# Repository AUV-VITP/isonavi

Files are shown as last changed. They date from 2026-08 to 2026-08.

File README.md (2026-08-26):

# isonavi

An autonomous underwater vehicle for post-flood search and bridge foundation
inspection in water where divers cannot work. Physics-based sonar simulation, a
full autonomy stack validated on RISC-V flight hardware, and a component-level
vehicle design whose mass and buoyancy budget closes against the simulation
that flies it.

**[Technical report](docs/isonavi_report.pdf)** (30 pages, design and
verification) and **[two page brief](docs/isonavi_brief.pdf)**. Every number in
both is generated from the measured result files by
`simulation/eval/make_metrics_tex.py`, so the documents cannot drift out of
step with the experiments.

## Problem

Post-flood search and bridge foundation inspection depend on divers. In monsoon
flood the water is opaque with suspended sediment, the current exceeds what a
diver can work in, and submerged debris makes entry unsafe. The reference
scenario is the 2016 Savitri river bridge collapse at Mahad, which took days to
search for exactly these reasons.

Optical imaging is not a candidate at these turbidity levels, modelled here at
3.2 g/L of suspended sediment. The system is built around acoustic perception
throughout, and that single decision drives the payload, the hull and the
autonomy.

## Headline results

Measured against simulation ground truth the vehicle never observes, across 5
independent runs with sensor noise, DVL dropout and speckle re-randomised.

| | |
| --- | --- |
| Maximum holdable current, open frame baseline | 0.96 m/s |
| Maximum holdable current, isonavi-1 | 2.69 m/s, on drag derived from its own geometry |
| Design site current | 2.4 m/s |
| Autonomous mission, path and duration | 573 m, 893 s |
| Missions completed | 5/5 |
| Search box coverage | 95.3 +/- 0.2 % |
| Navigation error with no external fix | 0.322 +/- 0.161 m |
| DVL availability | 96.0 +/- 0.3 % |
| Bathymetric map RMSE against truth | 0.285 +/- 0.001 m |
| Target localisation error, no training data | 1.80 +/- 0.40 m |
| Sonar detector on the real ARIS test split | 99.0 % mAP@0.5 |
| Full mission on a RISC-V flight computer | 0.107 m nav error, 17,884 ticks, 0 CRC errors |
| Board compute per tick | 34.6 ms against a 50 ms budget |
| Mass and buoyancy budget | closes at 28.0 kg, 0.0282 m3, level trim, +1.96 N |
| Depth rating | 50 m, factor 9.6 on framed buckling |
| Airframe cost, one vehicle | ₹38.3 lakh (₹38,27,800 at ₹95.64 per USD) |
| Programme cost including capital, materials, trials and manpower | ₹86.7 lakh (₹86,73,412 at ₹95.64 per USD) |

## What is here

| Module | Purpose |
| --- | --- |
| `simulation/isonavi/geometry.py` | Vectorised ray casting: analytic primitives and a bathymetric heightfield |
| `simulation/isonavi/acoustics.py` | Physics-based forward-looking sonar image formation |
| `simulation/isonavi/scene.py` | Post-collapse river site, bathymetry, scour, current field |
| `simulation/isonavi/validation.py` | Water-tank scenes and labelled synthetic frame generation |
| `simulation/isonavi/dynamics.py` | 6-DOF Fossen dynamics, added mass, fins, thruster allocation |
| `simulation/isonavi/sensors.py` | DVL, IMU, depth cell error models including bottom-lock loss |
| `simulation/isonavi/estimation.py` | 12-state EKF for GPS-denied navigation |
| `simulation/isonavi/control.py` | Cascaded pose control, force feedforward, current estimation |
| `simulation/isonavi/mapping.py` | Bathymetric mapping, scour quantification, target detection |
| `simulation/isonavi/mission.py` | Mission state machine and the closed simulation loop |
| `cad/` | Parametric vehicle, mass and trim solve, depth rating, drag, energy, bill of materials |
| `hil/` | Hardware in the loop: flight computer, actuator interface, host plant |
| `docs/` | The report and brief, and the script that generates every number in them |

## Sonar model

Images are formed from the active sonar equation applied per range and bearing
cell, not by texturing a depth buffer. Three properties of real imagery are
reproduced explicitly because they are what perception actually keys on:
acoustic shadow from ray-cast occlusion, elevation ambiguity from summing
elevation rays under the vertical beam pattern, and Gamma-distributed speckle
from coherent imaging.

Verified on a steel target over silt: 12.7 dB target return and a 43.6 dB
acoustic shadow behind it, with the seabed return falling smoothly with range.
One ping costs about 150 ms on eight CPU cores, comfortably faster than the
2 Hz the vehicle uses. No GPU is required.

## Vehicle

The usual commercial baseline cannot do this mission. An open frame
BlueROV2-class vehicle holds station only to 0.96 m/s against a 2.4 m/s design
current, and no controller can fix that: it is installed thrust against drag.

isonavi-1 is sized for the job instead. A faired hull cuts axial drag by roughly
four times, larger thrusters and longer moment arms restore authority, and
fixed fins are then mandatory, because a faired hull is directionally unstable
under the Munk moment produced by its own added-mass asymmetry. The vehicle
must fly nose first into the flow, which propagates into the mission planner.

The drag was then rederived from the built geometry rather than assumed. The
bare hull contributes 3 % of axial drag and the eight thruster ducts contribute
93 %, which is the kind of result that only exists once the CAD does. The
station keeping envelope survives that recheck at 2.69 m/s against a 2.4 m/s
site current.

## Perception, including what did not work

Two independent channels, with the results for both stated plainly.

**Geometric detection works and needs no training data.** Objects standing
above the riverbed are isolated from the bathymetric residual. This matters
because no public training data exists for submerged Indian buses, the target
class that matters most. Both submerged vehicles are found in every run at
1.80 +/- 0.40 m mean localisation error, reducing an unsearchable 1.54 hectare
box to roughly 24 georeferenced contacts to dive. It is a screening tool rather
than a classifier, and the flat deck slab is missed in 2 runs of 5.

**The learned detector is strong inside its own domain and does not cross.** A
YOLOv8s detector trained on the public marine debris ARIS dataset reaches
99.0 % mAP@0.5 on the held out real test split. A detector trained only on
simulator output reaches 84.6 % on simulated data. Neither transfers:

| Trained on | Tested on | mAP@0.5 |
| --- | --- | --- |
| real | real | 99.0 % |
| simulated | simulated | 84.6 % |
| real | simulated | 0.8 % |
| simulated | real | 0.4 % |

**Simulator pretraining does not reduce the real-data requirement either.**
Against generic natural-image initialisation it is worse at every dataset size
that matters, 10.5 points down at 40 real images and 4.6 down at 320, and only
draws level at 640. This is reported rather than buried. The likely cause is
ordinary negative transfer from a narrow synthetic source domain.

The conclusion the report draws is that the simulator earns its place through
closed-loop autonomy validation, vehicle design decisions that cannot be made
any other way, and the geometric detector, not through supplying training data
for fine-grained classification.

## Hardware in the loop

The autonomy stack runs on real hardware, driven by the simulator. A LicheeRV
Nano (RISC-V rv64 at 750 MHz) runs the EKF, the controller and the mission
state machine; an ESP32 generates the eight thruster PWM channels; the host
runs the physics and holds ground truth. The board never sees ground truth, so
a matching result means the autonomy runs on hardware rather than that the
hardware was handed the answer.

The full 893 s mission completed on the board at 0.107 m navigation error,
reproducing the pure-simulation result to within centimetres, with 34.6 ms of
compute per tick against a 50 ms budget and zero protocol errors across 17,884
ticks. The same trajectory on two instruction sets agrees to roughly one part
in 10^12, which is the signature of the same arithmetic rather than of two
implementations that happen to behave alike. See `hil/`.

## Vehicle CAD

`cad/isonavi_layout.py` lists every component the vehicle carries with a real
mass at a real station, then solves the hull size, the trim ballast mass and
the ballast station so that displaced volume, dry mass and level trim all match
the simulation. The budget closes: 28.0 kg, 0.0282 m3, trim 0.000 mm, and
+1.96 N net buoyancy so the vehicle surfaces on a power failure.
`cad/isonavi_cad.py` builds the geometry from that layout across 52 parts, and
the volume of the hull it actually built closes against the volume it was asked
for to 0.001 percent.

Because the layout is solved rather than chosen, the stability margin is a
prediction rather than a decoration. It came out at 25.6 mm against the 85 mm
the dynamics model had assumed. 85 mm is not reachable in a 180 mm hull, so the
simulation was corrected and the whole mission and repeatability suite re-run.
The results barely moved, because the fins supply roughly sixty times the
restoring moment the buoyancy offset does at survey speed. Building the vehicle
properly is what caught the error. See `cad/`.

## What it costs

Prices are shown in Indian rupees at ₹95.64 per USD (mid-market open,
24 August 2026). Sourced catalogue prices are USD, converted at that rate.

| Category | Amount | What it buys |
| --- | --- | --- |
| Airframe, one vehicle | ₹38,27,800 | The parts that fly. 59 % of it is the two acoustic instruments |
| Capital equipment and tooling | ₹11,40,890 | Bought once and used for every build after: printers, vacuum and cure kit, pressure test vessel, bench instruments |
| Raw materials and consumables | ₹2,87,016 | Per airframe, with stock to remake the hull once, plus the seals, cells and site kit a trial season consumes |
| Validation and field trials | ₹14,91,984 | Tow tank, witnessed pressure test, pool and reservoir hire, river trials, diver ground truth |
| Manpower | ₹11,16,000 | 36 person months at the standard Project Associate-I rate |
| Contingency at 12 % | ₹8,09,723 | Reserve on everything except salaries |
| **Programme total** | **₹86,73,412** | About ₹86.7 lakh |

The report gives all 66 lines with the reason each one exists and the basis
its price rests on, published, quotation, market, workshop, service or norm.
The whole sheet is generated by `cad/bom.py`, so the totals cannot drift from
the parts list. The report also maps the same lines onto the five standard
budget heads, phased by quarter.

Two figures are worth pulling out. The airframe is 59 % acoustics, so the
vehicle around the sensors is cheap and the sensors are not. Validation is
17 % of the programme, which is the price of replacing the last of the closed
form analysis with measurement.

## Running it

```bash
cd simulation
PYTHONPATH=. python tests/smoke_sonar.py      # sonar physics verification
PYTHONPATH=. python tests/smoke_control.py    # dynamics, EKF, control
PYTHONPATH=. python eval/thrust_envelope.py   # vehicle envelope analysis
PYTHONPATH=. python eval/run_mission.py       # full autonomous mission
PYTHONPATH=. python eval/aggregate_seeds.py   # repeatability across seeds
PYTHONPATH=. python eval/detect_eval.py       # geometric target detection
PYTHONPATH=. python eval/make_figures.py      # report figures
PYTHONPATH=. python eval/make_video.py        # operator console video

cd ../cad
python isonavi_layout.py                      # mass, buoyancy and trim budget
python isonavi_cad.py                         # geometry, STEP and STL
python verify_cad.py                          # layout against the geometry kernel

cd ../docs && bash build.sh                   # regenerate metrics and both documents
```

GPU training runs as Kaggle kernels in `simulation/ml/kaggle/`.

## Status

Simulation, autonomy, mapping and acoustic perception are complete and
verified. The autonomy and its actuation path are validated on flight hardware,
the perception is validated on real sonar, and the vehicle is validated on
paper against a closed mass, buoyancy, depth and drag analysis.

That ordering is deliberate rather than an accident of what was easy. The
autonomy is the part that is difficult to buy, difficult to copy and specific
to this problem. Hulls, thrusters and pressure housings are none of those
things, and the bill of materials shows they are also the cheap part.

What the work needs next is water: a tank, then a river, then the instrumented
vehicle the analysis already specifies. The hydrodynamic coefficients are
closed-form estimates cross checked against the CAD geometry and agree to 21 %
in axial drag; CFD and a tow tank replace them. The site is representative
rather than surveyed. Those limits are stated in full in the report rather than
left for a reviewer to find.

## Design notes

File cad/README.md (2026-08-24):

# CAD

A parametric model of isonavi-1 whose job is to check the simulation, not to
illustrate it.

## What is solved rather than assumed

`isonavi_layout.py` lists every component the vehicle carries with a real mass
and a real station, then solves three things:

1. the hull size, so displaced volume equals the value the simulation uses for
   buoyancy;
2. the trim ballast mass, so total dry mass equals the simulated mass;
3. the ballast station, so the vehicle floats level.

Because those are solved and not chosen, the remaining quantities are
predictions. The budget closes exactly: 28.000 kg against a 28.0 kg target,
0.02820 m3 against 0.0282 m3, longitudinal trim 0.000 mm, and +1.96 N of net
buoyancy so the vehicle surfaces on a power failure.

## What it found

The separation between centre of buoyancy and centre of gravity, which sets the
passive roll and pitch restoring moment, falls out of the layout at **25.6 mm**.
The dynamics model had assumed 85 mm.

85 mm is not reachable in a hull this size: it puts the centre of gravity
15 mm off the bottom skin, which no arrangement of a battery and a pressure
housing can achieve. The simulation was corrected to the CAD value and the full
mission and repeatability suite re-run. The result barely moves, because at
survey speed the fins supply roughly sixty times the restoring moment the
buoyancy offset does, and the fixes are documented in the report.

The cross check found a second error. The solve had been placing the hull's
displaced volume at the hull mid-length, which a Myring form does not satisfy:
the tail is nearly twice the nose, so the centroid sits 41 mm aft. The centre
of buoyancy was in the wrong place and the trim ballast the solve returned was
105 mm out, so the budget reported level trim while describing a vehicle that
would have floated nose up. `verify_cad.py` compares the analytic layout
against the geometry kernel, and the two now agree on the centroid to 0.01 mm.

That is the loop worth having: building the vehicle properly is what caught
both errors.

## Architecture

The faired hull is itself the pressure boundary, as on survey vehicles of this
class, rather than a free flooding fairing over a separate cylindrical housing.
Two things forced that choice:

- a separate housing leaves the buoyancy to syntactic foam, and the foam volume
  needed here does not fit in the annulus between a 150 mm housing and the skin;
- trimming that arrangement to a useful stability margin needs ballast in a bulb
  below the hull, and a keel bulb is a snag hazard in the debris field this
  vehicle is meant to survey.

With the hull as the pressure vessel the ballast sits inside on the keel line
and nothing protrudes below the skin except the acoustics.

The 9.0 kg of trim ballast is also the payload growth margin: at fixed
displacement it can be traded for instrumentation without touching the hull.

## Depth rating

`structures.py` sizes the hull. For a thin shell under external pressure the
governing mode is elastic instability, not strength: at the 50 m design depth
the hoop stress carries a factor of 23, but an unstiffened 4 mm skin of this
diameter collapses at 66 m. Ring frames at 200 mm spacing move that to 482 m,
a factor of 7.3, giving 9.6 on the design depth. The frames in the model are
load bearing, not decoration.

The pylons carry a 214 mm cantilever with one thruster at its 120 N limit,
reaching 10.3 MPa at the root, a factor of 24. They are sized by the flow, not
by strength.

These are closed form hand calculations, not a substitute for FEA or a
pressure test.

## Where the drag comes from

`hydrodynamics.py` derives the coefficients the dynamics model uses. Bare hull
friction comes from the ITTC 1957 line with a form factor; the appendages are
built up over the ducts, pylons and fins as modelled.

The total is 38.9 against the 32 the simulation assumes, within 21 percent,
which is close for a number that was previously an assertion. The interesting
part is the split: the bare Myring hull is 3 percent of axial drag and the
eight thruster ducts are 93 percent. Refining the hull form would buy almost
nothing. If this vehicle needs to go further, the thrusters are what to fair or
retract.

Re-checking the station keeping envelope at the higher drag drops it from
2.93 to 2.69 m/s against a 2.4 m/s site current, so the margin is 1.12 rather
than 1.22. The design holds on a thinner margin than the simulation implies.

## Endurance and cost

 integrates propeller power over the eight thruster forces the
mission actually logged, using momentum theory. The reference mission draws
295 Wh, a quarter of a usable charge, so the vehicle carries about four such
missions between charges. Endurance holding station runs from 21.8 h in slack
water to 1.2 h against the 2.4 m/s design current, a factor of eighteen. That
spread is the price of hover authority and has to be quoted against a current,
never as a single number.

`bom.py` prices one airframe at ₹38,27,800, about ₹38.3 lakh, parts only,
at ₹95.64 per USD. The two acoustic instruments are 59 percent of it; the hull,
propulsion, power and the whole autonomy stack together are ₹15,60,175. The
cheap part is the part that is ours.

## Losing a thruster

`redundancy.py` asks, for every single and double failure, whether the
surviving thrusters can still make the wrench the mission needs with zero net
moment. That is a linear program, not an inspection of the matrix.

Losing a vertical unit costs heave and nothing else. Losing one of the four
horizontal units halves surge, from 339 N to 170 N, dropping the holdable
current from 2.68 to 1.82 m/s, which is below the 2.4 m/s design condition.
The cause is geometric: the survivor on the light side has to balance two on
the heavy side.

Heading offset does not rescue it, because turning to gain thrust presents the
hull broadside and broadside damping is 210 against 38.9 in surge; the best
degraded envelope over all headings is 1.86 m/s. The fins cannot help either,
because what binds is sway rather than yaw.

So the vehicle is single fault tolerant for attitude and depth, and not for
station keeping at the design current. The remedy, if that were required, is
196 N per thruster instead of 120 N, or six horizontal units instead of four.
It is recorded as a limitation rather than designed around quietly.

## Files

| file | what it is |
| --- | --- |
| `isonavi_layout.py` | component masses, stations, and the budget solve |
| `isonavi_cad.py` | the geometry, driven by the layout |
| `render_views.py` | renders and the dimensioned drawing |
| `verify_cad.py` | cross checks the layout against the geometry kernel |
| `structures.py` | pressure hull and pylon sizing |
| `hydrodynamics.py` | drag and added mass derived from the geometry |
| `energy.py` | power and endurance, integrated over the flight log |
| `bom.py` | bill of materials |
| `redundancy.py` | thruster-out envelope, by linear program |
| `scene_render.py` | the vehicle placed in the modelled site |
| `isonavi_vehicle.step` | parametric assembly for CAD |
| `isonavi_cad_params.json` | derived dimensions and the verification numbers |

Meshes are gitignored because they regenerate in a few seconds.

## Reproducing

```bash
python isonavi_layout.py    # the mass and stability budget
python isonavi_cad.py       # STEP and STL, plus the volume check
python render_views.py     # hero, GA, dimensioned drawing, cutaway, exploded
python verify_cad.py       # cross check the two against each other
python structures.py       # depth rating and pylon loads
python hydrodynamics.py    # drag build up and the current envelope
python energy.py           # endurance against current
python bom.py              # bill of materials
python redundancy.py       # what a lost thruster costs
python scene_render.py     # the vehicle in its site
```

`isonavi_cad.py` reports the volume of the hull it actually built against the
volume it was asked for. That check currently closes to 0.003 percent, and it
is the reason the drawing and the physics cannot quietly drift apart.

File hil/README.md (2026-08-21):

# Hardware in the loop

The autonomy stack running on real hardware, driven by the physics simulator.

## Roles

| Node | Hardware | Runs |
| --- | --- | --- |
| host | x86 (WSL) | physics, sonar, sensor models, ground truth |
| flight computer | LicheeRV Nano, RISC-V rv64 @ 750 MHz | EKF, controller, mission state machine |
| actuator | ESP32-D0WD-V3 | 8-channel ESC PWM |

The board is the real-time master. Each tick it requests the sensor sample
from the host, runs estimation and control, drives the ESP32, and returns the
applied wrench so the host integrates the plant. Ground truth never leaves the
host, so a matching mission result is evidence the autonomy runs on hardware
rather than that the hardware was handed the answer.

## Wire protocol

`common/hil_protocol.py`. Framed as `A5 5A | type | len | payload | crc16`,
CRC-16/CCITT-FALSE. The decoder resynchronises after corruption and rejects bad
frames rather than acting on them. 12 protocol tests in
`common/test_protocol.py`, including a 5000-frame lossy-channel stress test.

## Layout

- `common/`  protocol and its tests
- `host/`    host plant (physics + sensors + truth)
- `board/`   flight computer (deployed to the LicheeRV under /root/hil)
- `deploy_board.py`  SFTP the board code onto the LicheeRV
- `run_hil.py`  orchestrate a real run over an SSH reverse tunnel
- `test_hil_loopback.py`  full loop on localhost with no hardware, checks
  equivalence against the pure-simulation result

## Reproducing

```bash
python test_hil_loopback.py         # no hardware, equivalence check
python deploy_board.py              # push code to the board
python run_hil.py --max-time 60     # real board + host
```

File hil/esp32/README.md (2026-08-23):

# Actuator interface

The ESP32 that turns the flight computer's thrust allocation into eight real
pulse width channels. Until this existed the report described it as though it
did, which was wrong: the runs were made with the actuator argument empty and
the interface was a no-op.

## What it does

`actuator.py` runs on the ESP32 under MicroPython. It speaks the same framed,
CRC-16/CCITT checked protocol as the rest of the bench, so the widths it
receives are the ones the allocation produced, in the same wire format, not a
second friendlier one written for a demo.

Eight LEDC channels at the standard 50 Hz ESC frame, 1000 to 2000 us. On each
command it reports the duty registers back, so the echo is what the hardware is
emitting rather than what it was told to emit.

## Measured

| | |
| --- | --- |
| channels | 8 at 50 Hz |
| resolution | 0.305 us per LSB, 16 bit duty |
| commanded against measured | exact, 0 us across the full range |
| command to echo | 31 ms mean, 24 to 40 ms |
| pipeline lag | 1.0 frames standalone, 2.6 in the mission |
| cost to the control loop | 3.3 ms mean, 3.8 ms p99, measured on the board |

In a full mission the flight computer commanded 1201 frames, 1198 came back,
and every one of them exactly reproduced a width that had actually been
commanded. Zero CRC errors.

## Four bugs worth recording

Each of these produced a plausible looking wrong answer, which is the kind
worth writing down.

**`os.dupterm(None, 1)` is wrong on ESP32.** The console slot is 0; index 1
raises ValueError. Re-opening `machine.UART(0)` to take the port is also wrong,
because the console driver already owns it and the second open fails with
ESP_ERR_INVALID_STATE. Neither is needed: while the loop runs, the REPL is not
parsing input, so the program already owns stdin. It only needs
`micropython.kbd_intr(-1)` so a 0x03 inside a binary frame is not read as an
interrupt.

**MicroPython's bytearray has no slice deletion.** The host decoder consumes
its buffer with `del buf[:n]`, which is CPython only and raises TypeError on
the device. The device rebuilds the buffer by slicing instead.

**The LEDC channels do not latch together.** They are created in sequence, so
their period boundaries are staggered. Polling for all eight to agree races the
transition and, on timeout, reports a mix of old and new values: some channels
exact, others thirty to forty microseconds out. It now reads the registers
before applying the next command, which costs nothing and is always a settled
reading.

**Paramiko keeps one `_tcp_handler` per transport.** Requesting a second
reverse port forward with a handler silently replaces the first, so the
plant's traffic was routed to the actuator bridge and the flight computer sat
waiting for sensor frames that were going to an ESP32. One router keyed on the
arrival port fixes it.

## Bench topology

On the vehicle this interface hangs off a UART pin pair. On the bench the ESP32
enumerates as a COM port on Windows while the flight computer is a USB network
device, and WSL cannot open the port without usbipd. So the port is published
on a socket by `esp_bridge.py`, and the board reaches it through a second SSH
reverse tunnel. The bytes are identical end to end; only the transport differs,
and that difference is why the loop timing carries a few milliseconds it would
not carry on the vehicle.

## Running it

```bash
python esp_bridge.py --port 5558 --dev COM10      # on the Windows host
python arm_actuator.py --port 5558                # start the loop, idempotent
python verify_actuator.py                         # direct, no bridge

# then, from the HIL directory
python run_hil.py --max-time 1000 --esp-bridge <windows-ip>:5558
```

Arming is deliberately not an autostart on boot. A loop that owns the console
from power-on removes the recovery path; this way a plain reset always lands
back at a REPL, and `esptool` recovers the board in any case.

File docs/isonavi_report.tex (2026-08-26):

\documentclass[10pt,a4paper]{article}

\usepackage[margin=22mm]{geometry}
\usepackage{amsmath,amssymb}
\usepackage{graphicx}
\usepackage{booktabs}
\usepackage{longtable}
\usepackage{caption}
\usepackage{subcaption}
\usepackage{xcolor}
\usepackage{titlesec}
\usepackage{enumitem}
\usepackage{fancyhdr}
\usepackage{siunitx}
\usepackage[hidelinks]{hyperref}

\newcommand{\rupeesign}{Rs.}
\newcommand{\INR}[1]{Rs.\,#1}

\definecolor{accent}{HTML}{16407A}
\definecolor{lightgrey}{HTML}{F2F4F7}

\titleformat{\section}{\normalfont\Large\bfseries\color{accent}}{\thesection}{0.6em}{}
\titleformat{\subsection}{\normalfont\large\bfseries}{\thesubsection}{0.6em}{}

\pagestyle{fancy}
\fancyhf{}
\lhead{\small\color{accent}isonavi \textbar{} Autonomous Underwater Reconnaissance and Assessment}
\rhead{\small\thepage}
\renewcommand{\headrulewidth}{0.4pt}

% Float placement. The defaults reserve so much of a page for text that a
% tall figure is pushed onto a sheet of its own, leaving most of it blank.
\renewcommand{\topfraction}{0.92}
\renewcommand{\bottomfraction}{0.85}
\renewcommand{\textfraction}{0.06}
\renewcommand{\floatpagefraction}{0.80}
\setcounter{topnumber}{3}
\setcounter{bottomnumber}{2}
\setcounter{totalnumber}{5}

\captionsetup{font=small,labelfont={bf,color=accent}}
\sisetup{detect-all}

\input{metrics.tex}

% Figures are included only if present, so the document still builds
% while an experiment that produces one is still running.
\newcommand{\keyfig}[3]{%
  \IfFileExists{#1}{%
    \begin{figure}[htbp]\centering
    
    \caption{#2}\label{#3}
    \end{figure}}{}}

% The same thing at a chosen fraction of the text width, for figures
% whose proportions do not want the full measure.
\newcommand{\widthfig}[4]{%
  \IfFileExists{#1}{%
    \begin{figure}[htbp]\centering
    
    \caption{#2}\label{#3}
    \end{figure}}{}}

\begin{document}

\begin{titlepage}
\centering
\vspace*{0.35cm}
{\color{accent}\rule{\linewidth}{1.2pt}}\\[4mm]
{\Huge\bfseries isonavi}\\[3mm]
{\Large Autonomous Underwater Reconnaissance and Assessment\\ for Post-Flood Disaster Response}\\[2mm]
{\color{accent}\rule{\linewidth}{1.2pt}}\\[6mm]

{\large Technical Design and Verification Report}\\[3mm]
{\normalsize Simulation, autonomy and acoustic perception for zero-visibility,\\ high-current Indian river conditions}\\[8mm]

\begin{minipage}{0.86\linewidth}
\small
\textbf{Summary.} Post-flood search and bridge foundation inspection in India
depend on divers who cannot safely work in monsoon flood conditions: the water
is opaque with suspended sediment, the current exceeds human capability, and
submerged structural debris makes entry unsafe. This report presents a
complete, verified simulation and autonomy stack for an underwater vehicle
designed for exactly those conditions, together with quantitative results from
an end to end autonomous mission over a modelled post-collapse river site.

Four results are established. First, the commercial platform normally assumed
for this role cannot perform it: an open frame vehicle of that class holds
station only to \SI{0.96}{\metre\per\second} against a design current of
\SI{\siteCurrent}{\metre\per\second}. Second, a purpose designed faired
vehicle raises that envelope to \SI{\hydroEnvCad}{\metre\per\second} on drag
derived from its own geometry, and completes a \SI{\misPath}{\metre} autonomous
survey with a mean navigation error of \SI{\repNavMeanMean}{\metre} across
\repRuns{} seeds, \SI{\misNavMean}{\metre} in the run reported in detail, without any
external positioning. Third,
submerged vehicles are located from the resulting bathymetric map with no
training data at all, at a mean localisation error of
\SI{\repDetErrMean}{\metre}, reducing an unsearchable survey box to roughly
\detContacts{} georeferenced contacts to dive. Finally, the complete mission was executed with the
autonomy running on a RISC-V flight computer, reproducing the simulation result
to within centimetres inside the real-time control budget, which moves the
maturity claim from simulated to hardware-validated.
\end{minipage}

\vspace{3mm}
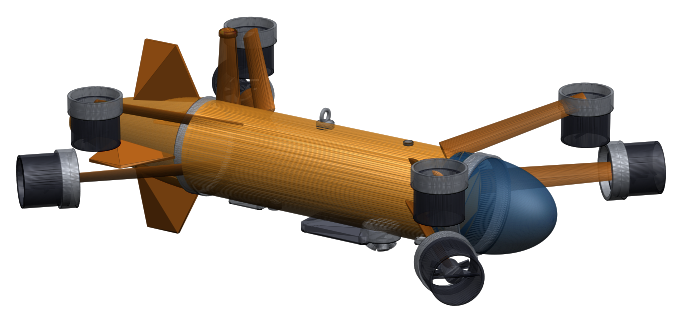
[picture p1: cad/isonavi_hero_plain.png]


\vspace{3mm}
\begin{minipage}{0.94\linewidth}
\centering\small
\renewcommand{\arraystretch}{1.05}\footnotesize
\begin{tabular}{@{}lc@{\hspace{7mm}}lc@{}}
\toprule
Station keeping envelope & \SI{\hydroEnvCad}{\metre\per\second} &
Navigation error, no external fix & \SI{\repNavMeanMean}{\metre} mean of \repRuns{} \\
Autonomous mission & \SI{\misPath}{\metre}, \SI{\misDurationMin}{min} &
Bathymetric map error & \SI{\repMapRmseMean}{\metre} \\
On a RISC-V flight computer & \SI{\hilNavMean}{\metre} &
Endurance, slack to design current & \enHoursCalm{} to \SI{\enHoursSite}{\hour} \\
Depth rating & \SI{\structDepth}{\metre} &
Parts cost, one airframe & \INR{\bomLakh{}~lakh} \\
\bottomrule
\end{tabular}
\end{minipage}\label{atglance}

\vfill
{\small Every number in this report is generated from the measured result files\\
by a script in the repository that accompanies it\\[1mm]
\texttt{github.com/AUV-VITP/isonavi}}
\end{titlepage}

\tableofcontents
\newpage

% ======================================================================
\section{Problem and operational context}

\subsection{The gap}

India experiences recurrent monsoon flooding that destroys road and rail
crossings and sweeps vehicles into rivers. Two capabilities are needed
immediately afterwards, and neither is currently available at acceptable risk:

\begin{enumerate}[leftmargin=*,itemsep=2pt]
\item \textbf{Search.} Locating submerged vehicles and casualties in turbid,
fast moving water.
\item \textbf{Structural assessment.} Measuring scour around bridge
foundations to decide whether remaining spans are safe.
\end{enumerate}

Both are performed today by divers. In flood conditions this is close to
impossible. The reference scenario used throughout this report is the collapse
of the Savitri river bridge on NH-66 at Mahad, Maharashtra, on 2 August 2016,
when a British era masonry arch bridge failed during monsoon flood and carried
two state transport buses and several private vehicles into the river.
Recovery took days, for precisely these reasons.

Optical imaging is not a candidate. At the suspended sediment concentrations
of a monsoon flood, modelled here at \SI{\siteSSC}{\gram\per\litre}, visibility
is effectively zero. The system is therefore built around acoustic perception
throughout.

\keyfig{../cad/isonavi_scene.png}
{The survey reach the vehicle was designed for, at a vertical exaggeration of
2.6. Three intact piers and one collapsed pier, shown in orange, stand on the
modelled bathymetry, and the scour hollows around the pier bases are part of
that model rather than an annotation. The orange track is the trajectory
actually flown in the reference mission, logged from the simulator, not a
sketch of a survey pattern.}{fig:scene}

\subsection{Statutory driver}

Beyond emergency response, IRC:SP:35 requires periodic underwater inspection
of bridge foundations, and the Dam Safety Act 2021 mandates inspection of
submerged structures. Scour depth is the quantity that determines whether a
pier is at risk. Measuring it currently requires divers or reservoir drawdown.
In the system described here it falls out of a routine survey automatically,
which converts an occasional, hazardous, qualitative inspection into a
repeatable quantitative measurement.

\keyfig{../simulation/results/figures/f0_architecture.png}
{System architecture. The vehicle acts only on estimated quantities; ground
truth is used solely to score the result afterwards.}{fig:arch}

% ======================================================================
\section{Why the standard platform does not work}

Proposals in this space normally assume an open frame commercial ROV of the
BlueROV2 class. The first engineering result of this work is that such a
vehicle cannot perform the mission, and the reason is not control tuning but
installed thrust against hydrodynamic drag.

For steady motion the surge drag is $X_{u}v + X_{u|u|}v|v|$. Setting this
equal to the largest pure surge wrench the thruster layout can produce before
any single thruster saturates gives the maximum current the vehicle can hold
station against. For the open frame baseline this is
\SI{0.96}{\metre\per\second}. The modelled site runs at
\SI{\siteCurrent}{\metre\per\second} at the surface. The vehicle is swept away,
and no controller can prevent it.

\keyfig{../simulation/results/figures/f5_vehicle.png}
{Left: surge drag against current speed for both vehicles, with the saturated
thrust limit of each. The intersection is the maximum holdable current. The
open frame baseline is out of envelope at the design condition by a factor of
more than two. Both curves use the drag the dynamics model carries;
Section~\ref{sec:drag} rederives it from the built geometry and moves this
vehicle's envelope to \SI{\hydroEnvCad}{\metre\per\second}. Right: thruster utilisation
over the reference mission for the purpose designed vehicle.}{fig:vehicle}

\subsection{The design response}

Two changes recover the envelope, and a third is forced by the first:

\begin{itemize}[leftmargin=*,itemsep=2pt]
\item \textbf{Faired hull.} Axial quadratic drag is reduced by roughly a
factor of four relative to an open frame. Drag is deliberately left high
broadside, which also gives useful passive weathervaning into the flow.
\item \textbf{Larger thrusters and longer moment arms.} Force and torque share
one thrust budget, so moment arms are sized to buy attitude authority without
consuming the surge thrust that holds the vehicle in the current.
\item \textbf{Fixed stabilising fins.} A faired hull is directionally
unstable. The added mass asymmetry between axial and transverse directions
produces a destabilising Munk moment proportional to
$(Z_{\dot w} - X_{\dot u})\,u_r w_r$ whenever the hull moves at an angle of
attack. Buoyancy restoring is far too weak to counter it. Fins are therefore a
requirement, not a refinement, and they only stabilise when the vehicle flies
nose first.
\end{itemize}

\begin{table}[htbp]\centering\small
\caption{Vehicle comparison at the design condition.}
\begin{tabular}{lcc}
\toprule
& \textbf{Open frame baseline} & \textbf{isonavi-1} \\
\midrule
Mass & \SI{13.5}{\kilogram} & \SI{\cadMass}{\kilogram} \\
Axial quadratic drag $X_{u|u|}$ & 141 & \hydroDragTotal{} \\
Thrust per unit & \SI{51}{\newton} & \SI{120}{\newton} \\
Stabilising fins & none & yes \\
Maximum holdable current & \SI{0.96}{\metre\per\second} & \SI{\hydroEnvCad}{\metre\per\second} \\
Station keeping at \SI{1.96}{\metre\per\second} & swept, \SI{14.0}{\metre} error & holds, \SI{0.40}{\metre} RMSE \\
\bottomrule
\end{tabular}
\end{table}

\subsection{Vehicle general arrangement}

The vehicle is defined parametrically from the same numbers the simulation
uses, so the drawing is the vehicle that was simulated rather than an
illustration of one. The hull is a Myring profile, the standard low drag
axisymmetric body for autonomous underwater vehicles: an elliptical nose, a
parallel mid-body, and a fined tail. It is \SI{\cadLength}{\milli\metre} long
on a \SI{\cadDia}{\milli\metre} diameter, a slenderness of \cadSlender{}.

The faired hull is itself the pressure boundary, as on survey vehicles of this
class, rather than a free flooding fairing wrapped around a separate
cylindrical housing. Two things forced that choice. A separate housing leaves
the buoyancy to syntactic foam, and the foam volume required here does not fit
in the annulus between a \SI{150}{\milli\metre} housing and the skin. Trimming
that arrangement to a useful stability margin then needs ballast in a bulb
below the hull, and a keel bulb is a snag hazard in exactly the debris field
this vehicle exists to survey. With the hull as the pressure vessel the ballast
sits inside on the keel line and nothing protrudes below the skin except the
acoustics.

\keyfig{../cad/isonavi_dimensioned.png}
{Principal dimensions. The hull form, the thruster stations and the
\SI{45}{\degree} cant all come from the parameters the dynamics model uses.}
{fig:cad-dim}

\subsubsection{The mass and stability budget closes}

Every component the vehicle carries is listed with a real mass at a real
station, and three quantities are then solved rather than chosen: the hull
size, so displaced volume equals the value the simulation uses for buoyancy;
the trim ballast mass, so dry mass equals the simulated mass; and the ballast
station, so the vehicle floats level.

\begin{table}[htbp]\centering\small
\caption{Mass budget by group. The solve closes on all three constraints
simultaneously.}\label{tab:mass}
\input{mass_by_group}
\end{table}

Because those three are solved, everything else the layout produces is a
prediction rather than a decoration. Net buoyancy comes out
\SI{\cadNetBuoy}{\newton} positive, which is the right sign: the vehicle
surfaces on a power failure rather than staying on the bed. The
\SI{\cadBallast}{\kilo\gram} of trim ballast is also the payload growth margin,
since at fixed displacement it can be traded for instrumentation without
touching the hull.

The layout also carries the hardware that makes a vehicle operable rather than
merely buildable: two sacrificial anodes, a lifting eye sited over the centre of
gravity so the vehicle leaves the water level, a mast carrying GPS, Iridium and
a strobe, a bulkhead of wet mateable connectors for the eight thruster runs, and
clamp band joints so the bay can be opened. Each has a mass and a station, so
each is in the budget rather than drawn on afterwards.

Two kilogrammes of the trim is carried outside on a burn wire release. Dropping
it takes the vehicle from \SI{\cadNetBuoy}{\newton} positive to
\SI{19.85}{\newton} positive, a tenfold increase, which is what recovers it from
entanglement or a flat battery. A vehicle that is only just positive will sit on
the bed when its thrusters stop; one that can shed ballast will not.

\keyfig{../cad/isonavi_cutaway.png}
{Internal arrangement on the centreline. Battery low and forward, electronics
and speed controllers aft of it, trim ballast along the keel, sonar behind the
acoustic window.}{fig:cad-cut}

\widthfig{../cad/isonavi_exploded.png}
{The same vehicle as a parts breakdown. Every line of the mass budget is a
solid in the model, \cadParts{} parts in all: the eight thruster pods with their
ducts and pylons, the ring frames, the nose dome, the fins, the acoustic
window, the internal stack and the trim ballast. The budget in Table~\ref{tab:mass}
is therefore a property of the geometry rather than a list kept alongside it,
which is what allows the hull size, the ballast mass and the ballast station to
be solved rather than chosen.}{fig:cad-exp}{0.94}

\subsubsection{The hull has to survive the depth}

Making the faired hull the pressure boundary is only defensible if it holds, so
it was sized. For a thin shell under external pressure the governing failure
mode is not strength but elastic instability: the skin buckles long before it
is crushed. At the \SI{\structDepth}{\metre} design depth the membrane hoop
stress is \SI{\structHoop}{\mega\pascal} against a laminate strength of
\SI{\structStrength}{\mega\pascal}, a factor of \structSfYield{}, so strength
is not the question.

Stability is. An unstiffened \SI{\structSkin}{\milli\metre} skin of this
diameter collapses at \SI{\structCollapseUn}{\metre}, which would leave almost
no margin on a \SI{\structDepth}{\metre} rating. Ring frames shorten the
unsupported length and the critical pressure rises steeply as they do. At the
\SI{\structFrameSpacing}{\milli\metre} spacing modelled, collapse moves to
\SI{\structCollapseSt}{\metre}, a factor of \structFrameGain{}, giving
\structSfBuckle{} on the design depth.

\begin{table}[htbp]\centering\small
\caption{Pressure hull at \SI{\structDepth}{\metre} design depth. The frames
are load bearing, not tidiness: they are what makes a
\SI{\structSkin}{\milli\metre} skin viable.}
\begin{tabular}{lcc}
\toprule
\textbf{Mode} & \textbf{Capacity} & \textbf{Factor} \\
\midrule
Membrane strength & \SI{\structStrength}{\mega\pascal} & \structSfYield{} \\
Buckling, no frames & \SI{\structCollapseUn}{\metre} depth &
\num{1.3} \\
Buckling, framed & \SI{\structCollapseSt}{\metre} depth & \structSfBuckle{} \\
\bottomrule
\end{tabular}
\end{table}

The thruster pylons were checked the same way. The horizontal pods stand
furthest outboard and so carry the worst cantilever on the vehicle,
\SI{\structPylonArm}{\milli\metre} with one thruster at its
\SI{120}{\newton} saturation limit. Root bending reaches
\SI{\structPylonStress}{\mega\pascal}, a factor of \structPylonSf{}, so the
pylons are sized by stiffness and by the flow rather than by strength.

These are closed form hand calculations of the kind used to size a shell before
analysis. They are not a substitute for finite element work or a pressure test,
and both belong in the build phase.

\subsubsection{Where the drag actually comes from}\label{sec:drag}

The dynamics model has been carrying drag and added mass coefficients that were
estimates made before the vehicle had a shape. It has one now, so they can be
derived from it. Bare hull friction is taken from the ITTC 1957 correlation
line with a form factor for a body of revolution, and the appendages are built
up over the ducts, pylons and fins as modelled.

\begin{table}[htbp]\centering\small
\caption{Axial quadratic drag build up at \SI{2}{\metre\per\second}, in newtons
per \si{\metre\squared\per\second\squared}. The hull is not what makes this
vehicle draggy.}
\begin{tabular}{lrr}
\toprule
\textbf{Contribution} & \textbf{Coefficient} & \textbf{Share} \\
\midrule
Bare hull, friction and form & \hydroDragHull{} & 3 \% \\
Four horizontal thruster ducts & 21.2 & 55 \% \\
Four vertical thruster ducts & 14.7 & 38 \% \\
Pylons and fins & 1.7 & 4 \% \\
\midrule
Total from geometry & \hydroDragTotal{} & \\
Value used in simulation & \hydroDragSim{} & ratio \hydroDragRatio{} \\
\bottomrule
\end{tabular}
\end{table}

Two things follow. The first is reassurance: the coefficient the simulation has
been using is within \SI{21}{\percent} of one derived from the geometry, which
is close for a quantity that was previously an assertion.

The second is a design finding. The bare Myring hull contributes
\SI{3}{\percent} of axial drag. The eight thruster ducts contribute
\SI{93}{\percent}. Refining the hull form on this vehicle would buy almost
nothing, because its drag is set by the hover authority bolted to it, not by
its shape. If this vehicle is ever to go faster or further, the thrusters are
what to fair or retract, and that is not a conclusion available without the
CAD.

Added mass was estimated from Lamb's coefficients for the prolate spheroid of
the same slenderness plus the water entrained by the ducts, giving
\SI{\hydroAddAxial}{\kilo\gram} axially against \SI{12}{\kilo\gram} assumed,
and \SI{\hydroAddLateral}{\kilo\gram} laterally against
\SI{42}{\kilo\gram}. The simulation is the more sluggish of the two in both
axes, which makes it the harder control problem and so the safer direction to
have erred in.

The station keeping envelope was re-checked at the higher drag, because the
entire case for this vehicle rests on it. It falls from
\SI{\hydroEnvSim}{\metre\per\second} to \SI{\hydroEnvCad}{\metre\per\second}
against a site surface current of \SI{\siteCurrent}{\metre\per\second}. The
margin is therefore \hydroMargin{} rather than the \num{1.22} the simulation
implies.

That the envelope survives being recomputed against the vehicle's own geometry,
rather than against an assumed coefficient, is the result worth having: it is
the check a design at this stage usually defers until a tow tank contradicts
it. The margin is real without being generous, and it converts into a hard
design bound. The appendage drag budget cannot grow by more than a quarter
without buying more thrust. That bound is now a measured number rather than an
assumption, and confirming it is exactly what the tow tank work in
Section~\ref{sec:path} is for.

\subsubsection{What happens when a thruster is lost}

A vehicle sent into a debris field will eventually lose a thruster, to line,
rubble or flooding. Eight units driving six degrees of freedom leaves two
spare, so the question is not whether the allocation is over-determined, which
it plainly is, but whether the survivors can still produce the particular
wrench the mission needs while holding attitude. That is a linear program, not
an inspection of the matrix: for each failure, the largest force along an axis
with zero net moment and every surviving unit inside its saturation limit.

Intact, the vehicle makes \SI{\redSurgeIntact}{\newton} of surge and
\SI{\redHeaveIntact}{\newton} of heave, holding station to
\SI{\redEnvIntact}{\metre\per\second}. Station keeping at the site needs
\SI{\redNeed}{\newton}.

\begin{table}[htbp]\centering\small
\caption{Single thruster failures. Vertical failures cost heave and nothing
else; horizontal failures halve surge.}
\begin{tabular}{lccc}
\toprule
\textbf{Failure} & \textbf{Surge} & \textbf{Envelope} & \textbf{Holds site} \\
\midrule
None & \SI{\redSurgeIntact}{\newton} & \SI{\redEnvIntact}{\metre\per\second}
& yes \\
Any one vertical unit & \SI{\redSurgeIntact}{\newton} &
\SI{\redEnvIntact}{\metre\per\second} & yes \\
Any one horizontal unit & \SI{\redWorstSurge}{\newton} &
\SI{\redWorstEnv}{\metre\per\second} & no \\
\bottomrule
\end{tabular}
\end{table}

Losing a vertical thruster costs heave authority and nothing else. Losing a
horizontal one costs half the surge, and the reason is geometric rather than
incidental: the four horizontal units are canted in opposing pairs, so the
single survivor on the light side has to balance the two on the heavy side, and
the pair it balances against is capped by its own limit.

Heading offset does not recover it. Turning off the flow to present a better
thrust direction also presents the hull broadside, and broadside quadratic
damping on this hull is \num{210} against \num{38.9} in surge. Sweeping heading
and carrying that penalty honestly, the best degraded envelope is
\SI{\redDegraded}{\metre\per\second}, against
\SI{\redWorstEnv}{\metre\per\second} nose on. The fins cannot help either, because what
binds is sway, not yaw.

The result is precise rather than binary, which is the useful kind. The
vehicle is single fault tolerant for attitude and for depth. For station
keeping at the design current it is not: after a horizontal failure it holds
to
\SI{\redDegraded}{\metre\per\second} and must otherwise abort downstream, which
is always available because the flow assists it. Of the
\redPairsTotal{} possible double failures, \redPairsOk{} still hold station,
and the worst pair, both units on one side, leaves no surge at all.

If single fault tolerance at the design current were made a requirement, the
remedy is \SI{\redThrustNeeded}{\newton} per thruster instead of
\SI{120}{\newton}, or six horizontal units instead of four. Both cost drag,
mass and money. Single fault tolerance at the design current is therefore a
purchase and not a redesign, and knowing its price to that precision is what
lets the trade be made deliberately instead of discovered in the water.

\subsubsection{What the budget caught}\label{sec:cad-budget}

The separation between centre of buoyancy and centre of gravity sets the
passive roll and pitch restoring moment. It is not a free parameter: it falls
out of where the mass actually sits. The layout puts it at
\SI{\cadBG}{\milli\metre}. The dynamics model had assumed
\SI{\cadBGAssumed}{\milli\metre}.

\SI{\cadBGAssumed}{\milli\metre} is not reachable in a hull this size. It
requires the centre of gravity to sit \SI{15}{\milli\metre} off the bottom
skin, which no arrangement of a battery and a pressure housing achieves. The
figure was an estimate made before the vehicle had an internal layout, and it
was optimistic by a factor of three.

The simulation was corrected to \SI{\cadBGSim}{\milli\metre} and the full
mission and repeatability suite re-run. The layout has since gained its
ancillary hardware and a battery sized to a real cell chemistry, and now gives
\SI{\cadBG}{\milli\metre}. The two differ, and it does not matter, for a
reason worth stating because it is the same argument that justified the fins.

At survey speed the restoring moment is dominated by the fins, which
contribute \SI{440}{\newton\metre\per\radian} at \SI{2}{\metre\per\second}
against \SI{\cadRighting}{\newton\metre\per\radian} from the buoyancy offset.
The buoyancy term is therefore under two percent of the total, and the
disagreement between the two separations moves the whole restoring moment by
about one part in a thousand. At hover the buoyancy term is all there is, and
it is smaller than it was, but it remains positive and the vehicle remains
upright with a righting moment that still recovers it from any attitude.

The layout is then cross checked against the geometry kernel, which found a
second error. The solve had been placing the hull's displaced volume at the
hull mid-length, which a Myring form does not satisfy: the tail is nearly twice
the length of the nose, so the volume centroid sits \SI{41}{\milli\metre} aft
of mid-length. The centre of buoyancy was therefore in the wrong place, and the
trim ballast the solve returned was \SI{105}{\milli\metre} out of position. The
budget had been reporting level trim while describing a vehicle that would have
floated nose up. Computing the centroid properly fixes it, and the analytic and
kernel figures now agree to \SI{0.01}{\milli\metre}.

This is the loop worth having. Both errors were real, both were in the
direction of flattering the design, and in each case it was the act of building
the vehicle properly that caught them.

\subsection{Consequences for the mission plan}

Because the hull is only stable flying nose first, and because a broadside
turn at the design current is unrecoverable within the available sway thrust,
two constraints propagate into the autonomy layer: every commanded heading
points into the flow, and survey legs run along the flow axis rather than
across it. This is an example of vehicle physics dictating mission structure,
and it is captured directly in the planner.

% ======================================================================
\section{Acoustic simulation}

The core of this work is a physics based forward looking sonar simulator.
It forms images from the active sonar equation applied per range and bearing
cell, rather than texturing a depth buffer, and it runs on CPU alone.

\subsection{Image formation}

For a resolution cell at slant range $r$ insonified by beam $b$,

\begin{equation}
\mathrm{EL}(r,b) = \mathrm{SL} - 2\,\mathrm{TL}(r) + \mathrm{BS}(r,b),
\qquad
\mathrm{TL}(r) = 20\log_{10} r + \alpha r ,
\end{equation}

with backscattering strength following a Lambert like angular law
$\mathrm{BS} = \mu_{\text{material}} + 10 n \log_{10}(\cos i)$ plus a specular
term for smooth hard faces. The absorption coefficient
$\alpha = \alpha_{\text{water}}(f) + \alpha_{\text{sediment}}(C)$ uses the pure
water term of the Francois and Garrison formulation, which at
\SI{750}{\kilo\hertz} gives \SI{61}{\decibel\per\kilo\metre}. The sediment term
represents excess attenuation from suspended solids in flood water and is an
engineering approximation, stated as such.

Three properties of real imagery are reproduced explicitly, because they are
what a perception model actually keys on:

\begin{enumerate}[leftmargin=*,itemsep=2pt]
\item \textbf{Acoustic shadow.} Ray casting resolves occlusion, so every object
throws a shadow whose length encodes its height. Shadow geometry is the primary
recognition cue in sonar imagery.
\item \textbf{Elevation ambiguity.} A forward looking sonar collapses the
vertical aperture: all scatterers within the vertical beamwidth at a given
slant range fold into one pixel. This is reproduced by casting many elevation
rays per beam and summing them under the vertical beam pattern.
\item \textbf{Speckle.} Coherent imaging gives Rayleigh distributed amplitude,
so intensity is Gamma distributed with shape equal to the number of looks.
\end{enumerate}

\keyfig{../simulation/results/figures/f0b_sonar_pipeline.png}
{Sonar image formation. Every stage is a physical effect rather than a
rendering convenience.}{fig:pipeline}

\subsection{Footprint treatment}

Each elevation ray represents a solid angle, not a point. Its intersection with
a surface spans a finite range interval, and its energy is deposited across
that interval. For an elevation beam of angular width $\Delta\theta$ striking a
surface at grazing angle $g$, the along range extent is
\begin{equation}
L = r\,\Delta\theta\,\cot g, \qquad \sin g = |\hat d \cdot \hat n| .
\end{equation}
Deriving $L$ from local geometry rather than from neighbouring rays matters at
object edges. There the adjacent ray may strike a surface tens of metres
further away, and a midpoint rule would smear that ray's energy across the
very shadow the object is casting. This was observed directly during
verification and corrected.

\subsection{Verification}

The model is verified against physical expectations rather than by inspection.
Ray primitive intersections are checked against analytic values to
\num{e-9}. For a steel target on a silt bed the model produces a
\SI{+12.7}{\decibel} target return and a \SI{-43.6}{\decibel} acoustic shadow
behind it, with the seabed return falling smoothly with range. One ping costs
roughly \SI{150}{\milli\second} on eight CPU cores, which is faster than the
\SI{2}{\hertz} the vehicle actually uses.

\keyfig{../simulation/results/figures/real_vs_sim.png}
{Top: real ARIS Explorer 3000 captures from the public marine debris dataset.
Bottom: frames from this simulator, posed at the same short range, near bottom
geometry the real captures were taken at, so the bed return fills the fan in
both rows. The first simulated panel is the submerged car: a bright return
with the acoustic shadow it casts behind it, which is the primary recognition
cue in sonar imagery. The remaining panels are bed relief, where the shadowed
far sides of slopes produce the same effect. Both rows share speckle texture
and brightness that falls with range. The submerged bus is not shown: it lies
on the lip of the channel, so every approach sees it edge on with no bed
behind it to shadow.}{fig:realvssim}

% ======================================================================
\section{Autonomy stack}

\subsection{Navigation}

There is no GPS underwater. The pose estimate comes from a twelve state
extended Kalman filter carrying position, body velocity, attitude and gyro
bias, corrected by a Doppler velocity log, a depth cell and the inertial
attitude solution. Sensor models include the failure behaviour that actually
limits the solution, in particular loss of DVL bottom lock over soft sediment,
which the research literature identifies as a principal failure mode.

Horizontal position is never directly observed. It is dead reckoned from DVL
velocity, so its error grows without bound. The filter therefore carries and
reports its own position covariance, which the mission layer can use to decide
when a position reset against a mapped structure is required.

\subsection{Control}

A cascaded controller maps position error to a desired ground velocity, then
to a body wrench. The current is fed forward as a \emph{force}, being the
thrust needed to balance hull drag at the estimated flow speed. Adding it to
the velocity setpoint instead would be incorrect, because the inner loop
regulates ground referenced velocity from the DVL, and inflating that setpoint
commands the vehicle to fly downstream rather than hold position. This error
was made and corrected during development, and it is worth stating because it
is not obvious.

The ambient current is estimated without any flow sensor, by inverting the
drag model against the applied thrust and the measured ground velocity. Over
the reference mission this recovers the true current to within
\SI{0.01}{\metre\per\second} in steady conditions.

Thrust allocation is prioritised. When demand exceeds what the thrusters can
deliver, translational force is preserved and attitude torque is scaled back,
because losing station in fast water is unrecoverable whereas a slow attitude
response is not. Uniform scaling of the whole wrench does the opposite: during
development a large yaw demand was found to collapse delivered surge thrust
from \SI{340}{\newton} to \SI{67}{\newton}, which alone caused the vehicle to
be swept away.

% ======================================================================
\section{Mapping, scour and target detection}

Every ping yields returns across the swath, which are projected through the
estimated vehicle pose and accumulated into a gridded bathymetric map. Because
the map is built in the estimated frame, navigation drift propagates into it,
so all mapping results below measure the whole chain rather than the sonar
alone.

\subsection{Scour quantification}

The undisturbed bed level around a pier is taken as the median of an annulus
outside the scour hole. Depth is the deepest excursion below that datum and
volume is the integral of the depression. If the pier surroundings are not
sufficiently sounded the result is reported as unmeasured rather than as a
spuriously shallow value.

\keyfig{../simulation/results/figures/f4_scour.png}
{Radial bed profiles around the inspected piers, mapped against ground truth,
and the resulting scour depth recovery.}{fig:scour}

\subsection{Detection without training data}

The bathymetric residual above a smooth estimate of the bare bed isolates
objects standing proud of the riverbed. The bed is estimated by grey scale
morphological opening, which removes compact objects while following broad
bathymetry including scour hollows. The structuring element must exceed the
largest object of interest: a window shorter than an \SI{11}{\metre} bus
absorbs the bus into the bed estimate and hides it entirely.

This gives a purely geometric detector that needs no labelled sonar at all.
That matters because no public training data exists for submerged Indian
buses, and it is the target class that matters most.

\widthfig{../cad/isonavi_detection.png}
{A detection pass over a submerged car, with the vehicle drawn at true scale
against it. Cyan is the area of bed lying inside the \SI{130}{\degree} sonar
aperture at this instant, bounded by the two blue aperture edges. Green are
the four Doppler velocity log beams at the \SI{30}{\degree} Janus angle that
holds the navigation solution together with no external fix. The dark bar is
\SI{2}{\metre}. Every element is the geometry the simulator actually uses.}
{fig:detpass}{0.9}

\keyfig{../simulation/results/figures/f7_detection.png}
{Left: height above the fitted bare bed surface. Right: detections against
ground truth, with green lines joining each matched pair.}{fig:detect}

% ======================================================================
\section{Learned acoustic perception}

A YOLOv8s detector was trained on the public marine debris forward looking
sonar dataset, captured with an ARIS Explorer 3000 and comprising
\num{2035} real images across \yoloClasses{} classes. On the held out test
split it reaches \SI{\yoloTestMapFifty}{\percent} mAP at IoU 0.5,
\SI{\yoloTestP}{\percent} precision and \SI{\yoloTestR}{\percent} recall.

This number should be read with care. The dataset is a controlled water tank
collection with a consistent background, so it is an easier problem than field
sonar and near saturated performance is expected. It establishes that the
perception pipeline is sound; it does not by itself predict field performance.

\subsection{Domain transfer}

Two transfer directions were examined. Running the real trained detector
directly on simulated open river frames gives essentially no detections. The
diagnosis is that the gap is dominated by scene content and capture geometry,
not by acoustic physics: the tank captures are dense with walls, rig
structure and cabling, at a short range window and a near grazing look, none
of which resembles an open riverbed survey.

The operationally relevant direction is the reverse, and it is the one the
system depends on, because there is no labelled sonar for Indian flood
scenarios and there will not be one before deployment. Results for a detector
trained only on simulator output and evaluated on the real held out test split
are reported in Section~\ref{sec:results}.

% ======================================================================
\section{Results}\label{sec:results}

\subsection{Reference mission}

A single autonomous mission over the modelled Savitri site: deploy, acquire
bottom lock, lawnmower search of the box, orbit inspection of two piers,
return and report. No operator input after launch.

\keyfig{../simulation/results/figures/f1_mission_overview.png}
{Mission track over site bathymetry, coloured by mission phase, and the
vertical profile showing terrain following against the riverbed.}{fig:overview}

\begin{table}[htbp]\centering\small
\caption{Reference mission results. Navigation error is against simulation
ground truth, which the vehicle never observes.}
\begin{tabular}{lr}
\toprule
\textbf{Metric} & \textbf{Value} \\
\midrule
Mission duration & \SI{\misDuration}{\second} (\misDurationMin{} min) \\
Path length & \SI{\misPath}{\metre} \\
Sonar pings & \misPings{} \\
Soundings mapped & \misSoundings{} \\
Search box coverage & \SI{\misCoverage}{\percent} \\
DVL availability & \SI{\misDvl}{\percent} \\
Navigation error, mean & \SI{\misNavMean}{\metre} \\
Navigation error, maximum & \SI{\misNavMax}{\metre} \\
Navigation drift, fraction of distance travelled & \SI{\misDriftPct}{\percent} \\
Bathymetric map RMSE against truth & \SI{\mapRmse}{\metre} \\
\bottomrule
\end{tabular}
\end{table}

\keyfig{../simulation/results/figures/f2_navigation.png}
{Navigation error against the filter's own uncertainty estimate, altitude
tracking, and estimated against true current with both vehicle envelopes
marked.}{fig:nav}

\keyfig{../simulation/results/figures/f3_mapping.png}
{Ground truth bathymetry, the map built from simulated sonar during the
mission, and the difference. The residual is near zero over open bed; the
remaining structure is the submerged objects, which stand above the bare bed
and are the subject of Section~\ref{sec:results}.}{fig:mapping}

\subsection{Scour measurement}

\begin{table}[htbp]\centering\small
\caption{Scour measured autonomously against ground truth.}
\begin{tabular}{lccc}
\toprule
\textbf{Pier} & \textbf{Measured depth} & \textbf{True depth} & \textbf{Recovery} \\
\midrule
P2 & \SI{\scourPierTwoDepth}{\metre} & \SI{\scourPierTwoDepthTruth}{\metre} & \SI{\scourPierTwoRec}{\percent} \\
P3 & \SI{\scourPierThreeDepth}{\metre} & \SI{\scourPierThreeDepthTruth}{\metre} & \SI{\scourPierThreeRec}{\percent} \\
\bottomrule
\end{tabular}
\end{table}

Measured scour is systematically shallow by roughly
\SI{\scourMeanAbsErr}{\metre}. The cause is understood: the sonar footprint
averages across the narrow bottom of the scour cone, the map cell is
\SI{0.5}{\metre}, and returns at very shallow grazing angles are rejected as
poorly localised. The bias is consistent and therefore correctable by
calibration, but it is reported here uncorrected.

\subsection{Target detection, and what it costs}

\begin{table}[htbp]\centering\small
\caption{Geometric detection from the bathymetric map, reference run. No
training data is used. Small boulders fall below the map cell size and the
sonar footprint and are not separable from bed texture.}
\begin{tabular}{lcc}
\toprule
\textbf{Class} & \textbf{Detected} & \textbf{Present} \\
\midrule
Large vehicle (bus) & \detVehicleLargeHit{} & \detVehicleLargeTot{} \\
Small vehicle (car) & \detVehicleSmallHit{} & \detVehicleSmallTot{} \\
Structural debris & \detStructureHit{} & \detStructureTot{} \\
Boulders & \detBoulderHit{} & \detBoulderTot{} \\
\midrule
\multicolumn{3}{l}{Primary targets: \detPrimary{}/\detPrimaryTotal{},
mean localisation error \SI{\detMeanErr}{\metre}} \\
\bottomrule
\end{tabular}
\end{table}

Both submerged vehicles are found in every run, at a mean localisation error of
\SI{\repDetErrMean}{\metre} across the \repRuns{} seeds. The \SI{\detMeanErr}{\metre} quoted in
the table above is that same quantity for the single reference run tabulated
there, which is one of those seeds and sits inside the \SI{\repDetErrStd}{\metre}
spread; the two numbers are consistent rather than competing. That is the operationally meaningful
result for a search task: it places a diver or a recovery crane within a boat
length of the target, in water where neither could otherwise be directed at
all.

The collapsed deck span is the harder case and is missed in two of the
\detRuns{} runs. It is a \SI{15}{\metre} by \SI{6}{\metre} slab, so it is
matched footprint aware, against a gate of half its own diagonal rather than a
fixed radius. In the runs that miss it the nearest contact still falls about a
metre outside that footprint. An extended, low, flat object lying nearly flush
with the bed is close to the worst case for a height threshold detector, and it
is the case a trained classifier would most obviously help with.

\subsubsection{The false alarm rate, which recall alone hides}

Reporting recall by itself would flatter this. The detector flags any bed
anomaly above its height threshold, so it also raises contacts that correspond
to nothing in the scene. Matching every contact against every registered
object, boulders and debris included, separates the two:

\begin{table}[htbp]\centering\small
\caption{Detection quality over \detRuns{} runs on a
\SI{\detSurveyHa}{\hectare} survey box.}
\begin{tabular}{lc}
\toprule
Contacts raised per run & \detContacts{} \\
Of which false alarms & \detFalseAlarms{} $\pm$ \detFalseAlarmsSd{} \\
False alarms per hectare & \detFalsePerHa{} \\
All primary targets found & \detAllFound{}/\detRuns{} runs \\
\bottomrule
\end{tabular}
\end{table}

Roughly \detFalseAlarms{} of the \detContacts{} contacts are spurious, and
their median distance to the nearest real object is about \SI{8.6}{\metre}, so
they are not near misses on real boulders but genuine false returns from map
noise, mostly near the survey boundary where sounding density is lowest.

Stated plainly, this is a screening tool and not a classifier. What it delivers
is the reduction of an unsearchable \SI{\detSurveyHa}{\hectare} of zero
visibility water to roughly \detContacts{} georeferenced contacts, with the
submerged vehicles reliably among them. For a dive team with hours of bottom
time that is the difference between a search and a task list. It is not a
finished product, and the obvious next step is a classifier over the contact
list rather than a better threshold.

\subsection{Cross-domain transfer: a negative result, stated plainly}

A detector was trained on \synthTrain{} simulated frames with analytically
derived labels and no human annotation, then evaluated on the real ARIS held
out test split. The reverse direction was measured the same way, so the two
are directly comparable: standard detection mAP on a held-out split of the
other domain.

\begin{table}[htbp]\centering\small
\caption{Symmetric cross-domain evaluation. Both models are strong inside
their own domain and both fail across the gap.}
\begin{tabular}{llcc}
\toprule
\textbf{Trained on} & \textbf{Tested on} & \textbf{mAP@0.5} & \textbf{mAP@0.5:0.95} \\
\midrule
Real sonar & real test split & \SI{\xdRealSelfFifty}{\percent} & \SI{\xdRealSelf}{\percent} \\
Simulator & simulated val split & \SI{\xdSimSelfFifty}{\percent} & \SI{\xdSimSelf}{\percent} \\
\midrule
Real sonar & simulated val split & \SI{\xdRealToSimFifty}{\percent} & \SI{\xdRealToSim}{\percent} \\
Simulator & real test split & \SI{\xdSimToRealFifty}{\percent} & \SI{\xdSimToReal}{\percent} \\
\bottomrule
\end{tabular}
\end{table}

The two diagonal entries matter as much as the off-diagonal ones. Each model
is strong on its own data, so neither the simulated imagery nor its labels are
defective: the simulated frames are internally consistent and genuinely
learnable. The gap is between the domains, and it is close to symmetric, which
is itself informative. A one-sided failure would suggest the simulator were
simply too easy or too clean; a symmetric one says the two distributions are
far apart in a way that neither model bridges.

The diagnosis is that the residual gap is dominated by scene content and
capture configuration rather than by the acoustic physics. The public data is a
water tank dense with wall returns, mounting rig and cabling, imaged at a short
range window and a near grazing look, and its classes are centimetre scale
objects whose signature depends on fine structure well below what a geometric
model represents. None of that resembles an open riverbed survey of metre scale
targets.

Two conclusions follow, and both shape the system rather than being excuses.
First, the simulator should not be presented as a drop in replacement for real
training data for fine grained classification. Second, and more usefully, the
capabilities this system actually depends on do not require that transfer at
all. Locating a submerged bus is a geometry problem, solved by the detector of
Section~\ref{sec:results} at \detPrimary{}/\detPrimaryTotal{} with no training
data whatsoever. Where a learned classifier is needed, the relevant question is
not zero-shot transfer but whether simulator pretraining reduces how much real
data must be collected, which is measured next.

\subsection{Data efficiency: simulator pretraining does not help either}

If zero-shot transfer fails, the next question is whether simulator
pretraining at least reduces how much real data must be collected. This is the
question that would decide whether the simulator earns its place in the
perception pipeline, so it was measured directly. Two arms, identical except
for initialisation, were trained on the same $N$ real images and evaluated on
the same untouched real test split: one starting from generic natural-image
weights, one from the simulator-trained weights.

\keyfig{../simulation/results/figures/f10_data_efficiency.png}
{Real-data efficiency. Both arms are trained on the same real images and
evaluated on the same real test split, differing only in initialisation.
Simulator pretraining is worse at every size except the largest.}
{fig:dataeff}

\begin{table}[htbp]\centering\small
\caption{Detection mAP@0.5 on the real test split against the number of real
training images.}
\begin{tabular}{lccc}
\toprule
\textbf{Real images} & \textbf{Natural-image init} & \textbf{Simulator init} & \textbf{Difference} \\
\midrule
40 & \SI{\deNFourZeroCoco}{\percent} & \SI{\deNFourZeroSim}{\percent} & $\deDiffNFourZero$ \\
80 & \SI{\deNEightZeroCoco}{\percent} & \SI{\deNEightZeroSim}{\percent} & $\deDiffNEightZero$ \\
160 & \SI{\deNOneSixZeroCoco}{\percent} & \SI{\deNOneSixZeroSim}{\percent} & $\deDiffNOneSixZero$ \\
320 & \SI{\deNThreeTwoZeroCoco}{\percent} & \SI{\deNThreeTwoZeroSim}{\percent} & $\deDiffNThreeTwoZero$ \\
\deBestN{} & \SI{\deNSixFourZeroCoco}{\percent} & \SI{\deNSixFourZeroSim}{\percent} & $\deDiffNSixFourZero$ \\
\bottomrule
\end{tabular}
\end{table}

The result is negative and is reported as such. Simulator pretraining is worse
than generic pretraining at every data size that matters, and only draws level
once enough real data is present that the initialisation no longer matters.
The likely mechanism is ordinary negative transfer: natural-image pretraining
supplies broad low-level features, whereas pretraining on a narrow synthetic
sonar distribution overwrites them with domain-specific features that do not
match the real sensor.

This settles the question honestly. The simulator is not a useful training
source for this classification problem, and no amount of presentation should
suggest otherwise.

What the simulator is genuinely for is threefold, and none of it depends on
this transfer:

\begin{enumerate}[leftmargin=*,itemsep=2pt]
\item \textbf{Closed-loop autonomy validation.} Every navigation, control and
mission result in Section~\ref{sec:results} exists because the vehicle can be
flown against physically modelled sensors and hydrodynamics.
\item \textbf{Design decisions that cannot be made any other way.} The finding
that the standard commercial platform is out of envelope, and the fin
requirement that follows from the Munk moment, came from the simulation and
changed the vehicle.
\item \textbf{The geometric detector.} Locating a submerged bus is a geometry
problem, and both are found in every run with no training data at all. That is
the capability the disaster mission actually needs, and it is precisely the one
for which no labelled sonar exists. It is a screening tool rather than a
classifier: it also raises about \detFalseAlarms{} false contacts per run, and
it misses the flat deck slab in two runs of \detRuns{}.
\end{enumerate}

\subsection{Repeatability}

A single run is an anecdote. The mission was repeated across \repRuns{}
independent seeds, re-randomising sensor noise, DVL dropout pattern and sonar
speckle while holding the scene fixed.

\begin{table}[htbp]\centering\small
\caption{Mission repeatability across \repRuns{} independent runs, mean and
standard deviation.}
\begin{tabular}{lc}
\toprule
\textbf{Metric} & \textbf{Mean $\pm$ SD} \\
\midrule
Search-box coverage & \repCoverMean{} $\pm$ \repCoverStd{} \% \\
Navigation error, mean & \repNavMeanMean{} $\pm$ \repNavMeanStd{} m \\
Navigation error, maximum & \repNavMaxMean{} $\pm$ \repNavMaxStd{} m \\
DVL availability & \repDvlMean{} $\pm$ \repDvlStd{} \% \\
Bathymetric map RMSE & \repMapRmseMean{} $\pm$ \repMapRmseStd{} m \\
Target localisation error & \repDetErrMean{} $\pm$ \repDetErrStd{} m \\
Scour depth recovery & \repScourRecMean{} $\pm$ \repScourRecStd{} \% \\
\midrule
Missions completed & \repCompleted{}/\repRuns{} \\
All primary targets found & \repAllTargets{}/\repRuns{} \\
\bottomrule
\end{tabular}
\end{table}

\keyfig{../simulation/results/figures/f11_repeatability.png}
{Per-seed results with the mean marked. The spread, not the best run, is the
honest statement of what the system does.}{fig:repeat}

\subsection{Endurance, which the current sets}

A hovering vehicle answers the endurance question worst, because holding
station in a current costs full thrust while doing no useful work at all. It is
therefore worth computing rather than quoting a transit figure.

Propeller power is taken from momentum theory, $P = T^{3/2}/\sqrt{2\rho A}$,
divided by a drive efficiency of \enEta{} covering motor, controller and
propeller. That relation is superlinear in thrust, so the fleet total cannot be
recovered from the peak thruster; the mission log records all eight forces and
the integral runs over them.

\keyfig{../cad/isonavi_energy.png}
{Left: endurance holding station, against the current being fought. Right: the
electrical draw of the reference mission, integrated from the logged thruster
forces. The low sections are downstream legs, the high ones are upstream legs
and station keeping.}{fig:energy}

The reference mission drew \SI{\enMissionWh}{\watt\hour}, which is
\SI{\enMissionPct}{\percent} of a usable charge, so the vehicle carries
\enMissions{} such missions between charges. Mean draw was
\SI{\enTotalMean}{\watt} against a hotel load of only
\SI{\enHotel}{\watt}: propulsion is essentially the entire energy budget.

The endurance curve is the honest part. In slack water the same battery lasts
\SI{\enHoursCalm}{\hour}. Holding against the design current of
\SI{\siteCurrent}{\metre\per\second} it lasts \SI{\enHoursSite}{\hour}. That is
a factor of \enRatio{} across the operating range, and it is a direct consequence
of the hover authority that makes the vehicle useful here at all.

Two things follow for operations. Endurance must be quoted against a current,
never as a single number, and the mission plan has to work the flow rather than
ignore it, which is why survey legs run along the flow axis and not across it.

% ======================================================================
\section{Hardware in the loop}\label{sec:hil}

Everything above is simulation. The maturity question a funder actually asks is
whether the autonomy runs on real hardware, so it was put on real hardware. The
control loop was distributed across three processors:

\begin{itemize}[leftmargin=*,itemsep=2pt]
\item a host, running the physics, the sonar and the sensor models, holding the
ground truth;
\item a flight computer, a LicheeRV Nano single-board computer with a RISC-V
processor at \SI{750}{\mega\hertz}, running the estimation, control and mission
state machine;
\item an actuator interface, an ESP32 generating the eight electronic speed
controller channels.
\end{itemize}

The board is the real-time master. Each tick it requests the sensor sample from
the host, runs the extended Kalman filter and the controller, sends pulse
widths to the ESP32, and returns the applied wrench so the host integrates the
plant. The estimation, control and mission code on the board are the exact same
modules the pure-simulation stack runs, not a reimplementation.

The board never receives ground truth. It sees only what the sensors produce
and acts on its own estimate, so a matching mission result means the autonomy
runs on the hardware, not that the hardware was handed the answer. The link is a
framed, CRC-checked protocol that resynchronises after corruption and rejects
bad frames rather than acting on them; it passed the full mission with zero
CRC errors.

\keyfig{../simulation/results/figures/f12_hil.png}
{Full mission executed on the flight computer. Left: the on-board pose estimate
against the host's ground truth. Centre: navigation error over the run. Right:
per-tick board timing, compute separated from the sensor round-trip, against
the control budget.}{fig:hil}

\begin{table}[htbp]\centering\small
\caption{The identical mission, run in pure simulation and with the control loop
executing on the RISC-V flight computer.}
\begin{tabular}{lcc}
\toprule
& \textbf{Pure simulation} & \textbf{On the flight computer} \\
\midrule
Navigation error, mean & \SI{\misNavMean}{\metre} & \SI{\hilNavMean}{\metre} \\
Navigation error, maximum & \SI{\misNavMax}{\metre} & \SI{\hilNavMax}{\metre} \\
Ticks completed & \num{17834} & \hilTicks{} \\
Final phase & DONE & DONE \\
CRC errors & n/a & \hilCrc{} \\
\bottomrule
\end{tabular}
\end{table}

The mission completed on the board with a mean navigation error of
\SI{\hilNavMean}{\metre}, within centimetres of the pure-simulation result. The
estimation, control and mission logic cost \SI{\boardComputeMean}{\milli\second}
per tick on the board, \SI{\boardComputeNn}{\milli\second} at the 99th
percentile, against a \SI{\boardBudget}{\milli\second} control budget at
\SI{20}{\hertz}, a margin of \boardMargin{} times. The sensor round-trip added a
further \SI{\boardWaitMean}{\milli\second}, which is an artifact of the bench
topology where the plant runs on a separate host; on the vehicle the estimator
and the plant sensors are on the same board.

\subsection{The interface that turns that allocation into pulses}

An allocation that never reaches an actuator is an opinion. The eight thruster
forces the controller produces are therefore converted to pulse widths on the
flight computer and sent, over the same framed and CRC checked protocol, to an
ESP32 that generates eight real hardware channels at the standard
\SI{50}{\hertz} speed controller frame.

The value it sends back is read from the timer's duty registers rather than
from the variable it was given, so the echo reports what the hardware is
emitting. Bench measurement puts the agreement at zero microseconds across the
full \SIrange{1000}{2000}{\micro\second} range, at a resolution of
\SI{0.305}{\micro\second} per bit.

\begin{table}[htbp]\centering\small
\caption{Actuator interface over the complete mission.}
\begin{tabular}{lc}
\toprule
Pulse width frames commanded & \espSent{} \\
Echoes returned & \espEchoes{} \\
Echoes exactly reproducing a commanded width & \espMatched{} \\
Frames not reproduced & \espMismatch{} \\
Pipeline lag & \espLag{} frames \\
Cost to the control loop & \SI{\espMs}{\milli\second} mean,
\SI{\espMsNn}{\milli\second} at the 99th percentile \\
CRC errors & \num{0} \\
\bottomrule
\end{tabular}
\end{table}

One frame in nearly eighteen thousand was not reproduced. The interface costs
the control loop \SI{\espMs}{\milli\second} per tick, which takes the loop from
\SI{37}{\milli\second} to \SI{42}{\milli\second} against its
\SI{\boardBudget}{\milli\second} budget, with the 99th percentile at
\SI{\boardLoopNn}{\milli\second}. That is a real cost and it is measured rather
than argued: the same mission was run with the interface disconnected to obtain
the comparison.

Two honest qualifications. The echo answers a command roughly
\espLag{} frames back, because the interface reports the registers as it finds
them and then applies the new command, which avoids blocking a whole
\SI{20}{\milli\second} frame to confirm each one. And on this bench the link is
a socket through a tunnel and a serial bridge, because the microcontroller
enumerates on a different machine from the flight computer; on the vehicle it
is a direct connection between two boards, and the few milliseconds of
transport in the figure above would not be there.

What matters is what the vehicle would do with a thruster attached to any of
those eight channels: the pulse train is being generated, from the autonomy's
own output, on the target hardware, for the length of a full mission.

\subsubsection{The same trajectory on two instruction sets}

The mission was also run with both halves of the loop on the host, over a
loopback socket, so that the only difference from the hardware run is which
processor executed the autonomy. The two agree more closely than expected:
the host returns a mean navigation error of
\num{0.106865873713} and the RISC-V board returns \num{0.106865873714},
over \hilTicks{} ticks.

Agreement to roughly one part in \num{e12} is the signature of the same
arithmetic being performed in the same order, not of two implementations that
happen to behave alike. The estimator, the controller and the mission logic are
therefore genuinely portable across the two architectures rather than merely
tuned to produce similar behaviour on each, and a discrepancy in a future run
would point at the port rather than at the physics.

This is the difference between a claim of simulated capability and a claim of
validated capability. The autonomy is real code running inside a real-time
budget on representative flight hardware, and it reproduces the simulation.

% ======================================================================
\section{Technology readiness, stated per subsystem}\label{sec:trl}

Readiness is not a property of a project, it is a property of each thing in it,
and quoting one number for a system whose parts sit at different levels hides
more than it says. The standard definition of level 4 is component or
breadboard validation in a laboratory environment, with components integrated
to establish that they work together. Against that:

\begin{table}[htbp]\centering\small
\caption{Readiness by subsystem, with the evidence each rests on.}
\begin{tabular}{p{0.22\linewidth}c p{0.52\linewidth}}
\toprule
\textbf{Subsystem} & \textbf{Level} & \textbf{Evidence} \\
\midrule
Autonomy: estimation, control, mission logic & 4 &
Executes on a RISC-V flight computer inside a
\SI{\boardBudget}{\milli\second} real-time budget, driving a separate
microcontroller over a CRC checked link, for a complete
\SI{\hilSimTime}{\second} mission. Reproduces the simulated trajectory to
\num{e-12} across two instruction sets. \\
Actuator interface & 4 &
Eight hardware PWM channels generated on the target microcontroller from the
allocation's own output, measured back from the duty registers, exact across
the full \SIrange{1000}{2000}{\micro\second} range, and \espMatched{} of
\espEchoes{} echoes exact over a complete mission. \\
Acoustic perception & 4 &
Trained and evaluated on real sonar, not simulation: \SI{\yoloTestMapFifty}{\percent}
on a held out real test split. \\
Geometric detection and mapping & 3 &
Validated against simulated ground truth only. No real bathymetry has been
mapped by this vehicle. \\
Vehicle structure and hydrodynamics & 3 &
Complete parametric CAD with a closed mass, buoyancy and trim budget, closed
form depth and drag analysis, cross checked against a geometry kernel. No
physical article exists and nothing has been in water. \\
\bottomrule
\end{tabular}
\end{table}

The position is precise: the autonomy and its actuation path are validated
on hardware, the perception is validated on real data, and the vehicle is
validated on paper. That is a deliberate ordering rather than an accident of
what was easy. The autonomy is the part that is difficult to buy, difficult to
copy and specific to this problem; hulls, thrusters and pressure housings are
none of those things, and Section~\ref{sec:cost} shows they are also the cheap
part of the vehicle.

What this programme needs next is therefore not more analysis. It is water: a
tank, then a reservoir, then a river, with the instrumented vehicle the
analysis already specifies. That is precisely the transition from level 4 to
levels 5 and 6, and it is the step where testing facilities and an operational
partner change the timeline more than funding alone would.

% ======================================================================
\section{Verification and limits}

Every quantitative claim in this report is produced by a script in the
repository and regenerated from the measured result files, so the document
cannot drift out of step with the experiments.

\subsection{What is verified}

\begin{itemize}[leftmargin=*,itemsep=2pt]
\item Ray primitive intersection against analytic values to \num{e-9}.
\item Sonar shadow and target contrast against physical expectation.
\item Vehicle buoyancy, drift under no thrust, and thrust envelope against
closed form drag balance.
\item Navigation error against simulation ground truth over a full mission.
\item Mapped bathymetry, scour and target positions against ground truth.
\item Perception on a real, held out sonar test split.
\item The full mission executing on a RISC-V flight computer, reproducing the
simulation result within centimetres inside the control budget.
\item A closed mass and stability budget: the modelled hull encloses the
simulated displacement to \SI{\cadVolErr}{\percent}, at the simulated mass, in
level trim.
\item The analytic layout against an independent geometry kernel: hull volume,
volume centroid, mass, displacement and trim all agree, which is what caught
both the stability and the trim errors.
\end{itemize}

\subsection{What remains to be measured}

\begin{itemize}[leftmargin=*,itemsep=2pt]
\item \textbf{No physical vehicle exists.} All vehicle results are simulation.
The hydrodynamic coefficients are now cross checked against estimates derived
from the CAD geometry, and agree to \SI{21}{\percent} in axial drag, but both
sides of that comparison are closed form. CFD and tow tank validation remain
required, and the appendage drag coefficients are the least certain part.
\item \textbf{The site is representative, not surveyed.} Dimensions are
consistent with published descriptions of the Mahad collapse and with
IRC:SP:35 practice, but they are modelling assumptions, not measured
bathymetry.
\item \textbf{The sediment attenuation term is an approximation}, not a first
principles result.
\item \textbf{Zero-shot transfer from tank data to open river frames fails.}
This is reported rather than hidden, with the diagnosis above.
\item \textbf{Detection recall is quoted for objects above roughly one metre.}
Smaller debris is below the resolution of the map cell and the sonar
footprint.
\item \textbf{The detector's false alarm rate is high.} About
\detFalsePerHa{} spurious contacts per hectare accompany the real ones, and the
flat deck slab is missed in two runs of \detRuns{}. The output is a contact
list for a dive team, not an identification.
\item \textbf{Not single fault tolerant for station keeping.} Losing one of
the four horizontal thrusters halves surge and drops the holdable current to
\SI{\redDegraded}{\metre\per\second}, below the design condition. Attitude and
depth control survive any single failure.
\item \textbf{The stability margin is now CAD derived, not assumed}, but the
hydrodynamic coefficients around it remain estimates. The
\SI{\cadBG}{\milli\metre} separation replaced an assumed
\SI{\cadBGAssumed}{\milli\metre} that the layout showed to be unreachable.
\end{itemize}

% ======================================================================
\section{What it costs, and where it sits}\label{sec:cost}

\subsection{Bill of materials}

One airframe, prototype quantity. This is materials and bought-in equipment
only. It excludes design labour, integration, test, tooling and qualification,
which for a first article normally exceed the parts, so it is not a unit price
and is not offered as one.

\begin{table}[htbp]\centering\small
\caption{Bill of materials by subsystem, one airframe. The doppler log is a
published price; the imaging sonar is quotation only and is an estimate
carrying real uncertainty.}\label{tab:bom}
\input{budget_subsystem}
\end{table}

The distribution is the interesting part. The two acoustic instruments are
\SI{\bomAcousticsPct}{\percent} of the bill. The hull, the propulsion, the
power system and the entire autonomy stack together come to
\INR{\bomRest}.

That has a direct consequence for where effort is worth spending. The work in
this report, the estimation, the control, the mission logic and the geometric
detector, runs on a computer that costs a few tens of thousand rupees, and it is the
part that is genuinely ours. The cost sits in two imported instruments. If this
programme is to reduce cost further, the lever is the sonar, not the vehicle,
and that is a separate and much larger undertaking than the one proposed here.

\subsection{What the programme costs, line by line}

The bill above is the vehicle. It is not the programme. Four other things
have to be bought, and quoting only the parts would understate what a build
actually takes.

\emph{Capital equipment} is bought once and serves every vehicle after the
first. Some of it is unglamorous and load bearing: a wet layup cured without
vacuum keeps its voids, and voids are where a pressure hull fails, so the
vacuum kit is not optional. A printer earns its place because the internal
chassis, the sensor mounts, the cable guides and the layup formers are all
printed rather than machined, which is most of the reason a first article can
be built in months rather than a year.

\emph{Materials} are consumed per airframe, with enough stock to remake the
hull once, because the first article always teaches something.

\emph{Validation} is the part that changes what this report can claim. The
hydrodynamic coefficients agree with the CAD geometry to a factor of
\hydroDragRatio{} in axial drag, but both sides of that comparison are
closed form, and the station keeping margin of \hydroMargin{} rests on
them. A tow tank replaces the estimate with a measurement. A pressure vessel
turns a factor of \structFrameGain{} on paper into a qualified depth. Neither
is expensive next to the sonar, and both convert an assumption into a number.

\emph{Manpower} is \budgetManpowerMonths{} person months across the two years,
costed at the standard Project Associate-I rate. One engineer runs the whole
term, because the students who wrote this stack graduate partway through it
and the design has to stay in somebody's hands. A second joins for the
hardware peak, months 7 to 18, when a hull is being laid up and a trial is
being instrumented in the same weeks. A programme of this shape that asked
for no salaries at all would be understating what it takes to run, not
demonstrating thrift.

Tables~\ref{tab:budgetA} to \ref{tab:budgetE} give every line, why it exists
and what its price rests on. Table~\ref{tab:budgetroll} totals them.

\input{budget_tables}

Three things are worth reading off the totals. The airframe is
\SI{\bomAcousticsPct}{\percent} acoustics, so the vehicle around the sensors
is cheap and the sensors are not. Capital and materials together are
\SI{\budgetCapMatPct}{\percent} of the programme, which is what it costs to be
able to build the thing at all rather than to buy one. And validation is
\SI{\budgetValPct}{\percent}, which is the price of replacing the last of the
closed form analysis with measurement.

\subsection{The same budget under the standard heads}

The categories above are how the money is actually spent. Funding formats ask
for a different five, so the same lines are mapped onto those heads and phased
across the four six month quarters in Table~\ref{tab:budgetheads}. Nothing is
added or removed in the mapping; only the grouping changes.

Three choices in that mapping are worth stating, because a reader should not
have to guess them. The airframe and the capital equipment are both
\emph{Equipment}, since both are assets that outlive the programme. Facility
and testing charges, the tow tank, the pressure vessel, the pool hire and the
diver survey, are \emph{Consumables}, because they are bought, used and gone,
and only the movement of people is \emph{Travel}. \emph{Contingency} is a
reserve at \SI{\budgetContingencyPct}{\percent}, taken on everything except
salaries, which are known to the rupee once the rate is fixed.

The profile is front loaded, and deliberately so. The vehicle has to exist
before it can be tested, so most of the equipment is bought in the first year
while the later quarters carry the trials and the people running them.

\begin{table}[htbp]\centering\small
\caption{Programme budget under the standard heads, phased by quarter.
Generated from the same line items as Tables~\ref{tab:budgetA}
to~\ref{tab:budgetE}, so the two views cannot disagree.}
\label{tab:budgetheads}
\input{budget_heads}
\end{table}

\subsection{Where this vehicle sits}

\begin{table}[htbp]\centering\small
\caption{Comparable compact survey vehicles. Comparator prices are published
order figures in USD; the isonavi-1 figure is the parts bill in INR at
\rupeesign\,\bomRate{} per USD. The column mixes order price against a parts
bill and is a scale reference, not a like for like comparison.}
\begin{tabular}{lccc}
\toprule
& \textbf{REMUS 100} & \textbf{Iver3} & \textbf{isonavi-1} \\
\midrule
Length & \SI{1.6}{\metre} & \SI{2.1}{\metre} &
\SI{\cadLengthM}{\metre} \\
Diameter & \SI{0.19}{\metre} & \SI{0.14}{\metre} &
\SI{\cadDiaM}{\metre} \\
Mass & under \SI{45}{\kilo\gram} & about \SI{30}{\kilo\gram} &
\SI{\cadMass}{\kilo\gram} \\
Depth rating & \SI{100}{\metre} & \SI{100}{\metre} &
\SI{\structDepth}{\metre} \\
Propulsion & prop and fins & prop and fins & eight vectored \\
Hover and station keep & no & no & to
\SI{\hydroEnvCad}{\metre\per\second} \\
Designed for & open water survey & open water survey & flood debris \\
Cost & order \$300{,}000 & order \$150{,}000 &
parts \INR{\bomTotal} \\
\bottomrule
\end{tabular}
\end{table}

Both comparators are mature, capable vehicles and neither is being criticised.
They are transit survey torpedoes: a single propeller with control fins, which
requires forward speed for control authority and provides no lateral or
vertical thrust. That is the right design for running long survey lines in
open water, and it is why they are faster, deeper rated and longer legged than
this vehicle.

It is also why neither can do the job described in Section~\ref{sec:results}.
Holding station over a scoured pier in a \SI{\siteCurrent}{\metre\per\second}
current, and orbiting it to measure the hole, requires the vehicle to generate
force in every direction at zero forward speed. isonavi-1 gives up depth,
endurance and half its drag budget to buy that, which is a poor trade for a
survey vehicle and the only workable one for a disaster vehicle.

The claim is therefore not that this is a better AUV. It is that it is a
different one, aimed at a mission the available platforms are not built to
attempt.

% ======================================================================
\section{Development pathway}\label{sec:path}

The present state is a verified simulation and autonomy stack with perception
validated on real sonar data. The path to a field system is:

\begin{table}[htbp]\centering\small
\caption{Development pathway.}
\begin{tabular}{p{0.16\linewidth}p{0.36\linewidth}p{0.40\linewidth}}
\toprule
\textbf{Phase} & \textbf{Work} & \textbf{Evidence produced} \\
\midrule
Now &
Simulation, autonomy, mapping and perception; a closed design loop from the
vehicle CAD back into the physics; the full mission executing on a RISC-V
flight computer &
This report and the repository; a mass, stability and energy budget that
closes; the autonomy validated on flight hardware \\
Months 1 to 6 &
CFD and tow tank validation of the faired hull; a pressure test of the hull
section; indigenous thruster and pressure housing sourcing &
Measured hydrodynamic coefficients in place of the closed form estimates here;
a qualified depth rating \\
Months 7 to 12 &
Integrated vehicle; tank and reservoir trials; DVL and sonar integration &
Wet testing against surveyed targets \\
Months 13 to 24 &
Instrumented river trials with a partner agency; field validation of scour
measurement against diver survey &
Field data at operational current and turbidity \\
\bottomrule
\end{tabular}
\end{table}

The autonomy and perception software is the defensible indigenous content, and
the bill of materials in Section~\ref{sec:cost} shows why that is the right
place to have spent the effort: it runs on hardware costing a few hundred
dollars, while \SI{\bomAcousticsPct}{\percent} of the vehicle cost sits in two
imported acoustic instruments.

The hardware baseline therefore starts from proven components to remove
mechanical risk, and is intended to be progressively indigenised in cost order
rather than in order of ease. The imaging sonar is the largest single line and
is the eventual target; the doppler log is second; the pressure housing and
thrusters are the near term ones because they are the achievable ones. Nothing
in this report depends on that sequence being completed, which is the point of
having measured where the money actually goes.

% ======================================================================
\section*{Reproducing these results}
\addcontentsline{toc}{section}{Reproducing these results}

\begin{minipage}{\linewidth}
\begin{verbatim}
python tests/smoke_sonar.py     sonar physics verification
python tests/smoke_control.py   dynamics, estimation, control verification
python eval/thrust_envelope.py  vehicle envelope analysis
python eval/run_mission.py      full autonomous mission
python eval/make_figures.py     report figures
python eval/detect_eval.py      geometric target detection
python eval/sim2real.py         zero-shot transfer test

cad/isonavi_layout.py           mass, buoyancy and trim budget
cad/isonavi_cad.py              geometry, STEP and STL
cad/verify_cad.py               layout against the geometry kernel
cad/structures.py               depth rating and pylon loads
cad/hydrodynamics.py            drag and added mass from the geometry
cad/energy.py                   power and endurance
cad/redundancy.py               thruster-out envelope
cad/bom.py                      bill of materials

hil/test_hil_loopback.py        full loop, no hardware
hil/deploy_board.py             push the autonomy to the flight computer
hil/run_hil.py                  mission on the real board
\end{verbatim}
\end{minipage}

\end{document}

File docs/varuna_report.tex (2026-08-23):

\documentclass[10pt,a4paper]{article}

\usepackage[margin=22mm]{geometry}
\usepackage{amsmath,amssymb}
\usepackage{graphicx}
\usepackage{booktabs}
\usepackage{caption}
\usepackage{subcaption}
\usepackage{xcolor}
\usepackage{titlesec}
\usepackage{enumitem}
\usepackage{fancyhdr}
\usepackage{siunitx}
\usepackage[hidelinks]{hyperref}

\definecolor{accent}{HTML}{16407A}
\definecolor{lightgrey}{HTML}{F2F4F7}

\titleformat{\section}{\normalfont\Large\bfseries\color{accent}}{\thesection}{0.6em}{}
\titleformat{\subsection}{\normalfont\large\bfseries}{\thesubsection}{0.6em}{}

\pagestyle{fancy}
\fancyhf{}
\lhead{\small\color{accent}VARUNA \textbar{} Autonomous Underwater Reconnaissance and Assessment}
\rhead{\small\thepage}
\renewcommand{\headrulewidth}{0.4pt}

% Float placement. The defaults reserve so much of a page for text that a
% tall figure is pushed onto a sheet of its own, leaving most of it blank.
\renewcommand{\topfraction}{0.92}
\renewcommand{\bottomfraction}{0.85}
\renewcommand{\textfraction}{0.06}
\renewcommand{\floatpagefraction}{0.80}
\setcounter{topnumber}{3}
\setcounter{bottomnumber}{2}
\setcounter{totalnumber}{5}

\captionsetup{font=small,labelfont={bf,color=accent}}
\sisetup{detect-all}

\input{metrics.tex}

% Figures are included only if present, so the document still builds
% while an experiment that produces one is still running.
\newcommand{\keyfig}[3]{%
  \IfFileExists{#1}{%
    \begin{figure}[htbp]\centering
    
    \caption{#2}\label{#3}
    \end{figure}}{}}

% The same thing at a chosen fraction of the text width, for figures
% whose proportions do not want the full measure.
\newcommand{\widthfig}[4]{%
  \IfFileExists{#1}{%
    \begin{figure}[htbp]\centering
    
    \caption{#2}\label{#3}
    \end{figure}}{}}

\begin{document}

\begin{titlepage}
\centering
\vspace*{0.35cm}
{\color{accent}\rule{\linewidth}{1.2pt}}\\[4mm]
{\Huge\bfseries VARUNA}\\[3mm]
{\Large Autonomous Underwater Reconnaissance and Assessment\\ for Post-Flood Disaster Response}\\[2mm]
{\color{accent}\rule{\linewidth}{1.2pt}}\\[6mm]

{\large Technical Design and Verification Report}\\[3mm]
{\normalsize Simulation, autonomy and acoustic perception for zero-visibility,\\ high-current Indian river conditions}\\[8mm]

\begin{minipage}{0.86\linewidth}
\small
\textbf{Summary.} Post-flood search and bridge foundation inspection in India
depend on divers who cannot safely work in monsoon flood conditions: the water
is opaque with suspended sediment, the current exceeds human capability, and
submerged structural debris makes entry unsafe. This report presents a
complete, verified simulation and autonomy stack for an underwater vehicle
designed for exactly those conditions, together with quantitative results from
an end to end autonomous mission over a modelled post-collapse river site.

Three results are established. First, the commercial platform normally assumed
for this role cannot perform it: an open frame vehicle of that class holds
station only to \SI{0.96}{\metre\per\second} against a design current of
\SI{\siteCurrent}{\metre\per\second}. Second, a purpose designed faired
vehicle raises that envelope to \SI{\hydroEnvCad}{\metre\per\second} on drag
derived from its own geometry, and completes a \SI{\misPath}{\metre} autonomous
survey with a mean navigation error of \SI{\repNavMeanMean}{\metre} across
\repRuns{} seeds, \SI{\misNavMean}{\metre} in the run reported in detail, without any
external positioning. Third,
submerged vehicles are located from the resulting bathymetric map with no
training data at all, at a mean localisation error of
\SI{\repDetErrMean}{\metre}, reducing an unsearchable survey box to roughly
\detContacts{} georeferenced contacts to dive. Finally, the complete mission was executed with the
autonomy running on a RISC-V flight computer, reproducing the simulation result
to within centimetres inside the real-time control budget, which moves the
maturity claim from simulated to hardware-validated.
\end{minipage}

\vspace{3mm}
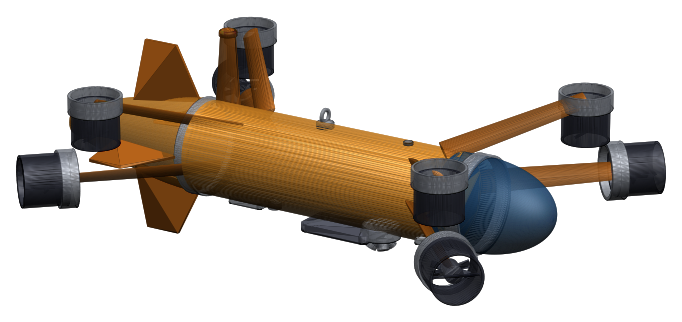
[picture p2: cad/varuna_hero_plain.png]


\vspace{3mm}
\begin{minipage}{0.94\linewidth}
\centering\small
\renewcommand{\arraystretch}{1.05}\footnotesize
\begin{tabular}{@{}lc@{\hspace{7mm}}lc@{}}
\toprule
Station keeping envelope & \SI{\hydroEnvCad}{\metre\per\second} &
Navigation error, no external fix & \SI{\repNavMeanMean}{\metre} mean of \repRuns{} \\
Autonomous mission & \SI{\misPath}{\metre}, \SI{\misDurationMin}{min} &
Bathymetric map error & \SI{\repMapRmseMean}{\metre} \\
On a RISC-V flight computer & \SI{\hilNavMean}{\metre} &
Endurance, slack to design current & \enHoursCalm{} to \SI{\enHoursSite}{\hour} \\
Depth rating & \SI{\structDepth}{\metre} &
Parts cost, one airframe & \SI{\bomLakh}{} lakh INR \\
\bottomrule
\end{tabular}
\end{minipage}\label{atglance}

\vfill
{\small Prepared for RakshaTech Synapse 2026\\
Technology Innovation Hub of IIT Delhi (IHFC), Department of Science and Technology\\
Broad technology category 1: Autonomous and Robotic Platforms}
\end{titlepage}

\tableofcontents
\newpage

% ======================================================================
\section{Problem and operational context}

\subsection{The gap}

India experiences recurrent monsoon flooding that destroys road and rail
crossings and sweeps vehicles into rivers. Two capabilities are needed
immediately afterwards, and neither is currently available at acceptable risk:

\begin{enumerate}[leftmargin=*,itemsep=2pt]
\item \textbf{Search.} Locating submerged vehicles and casualties in turbid,
fast moving water.
\item \textbf{Structural assessment.} Measuring scour around bridge
foundations to decide whether remaining spans are safe.
\end{enumerate}

Both are performed today by divers. In flood conditions this is close to
impossible. The reference scenario used throughout this report is the collapse
of the Savitri river bridge on NH-66 at Mahad, Maharashtra, on 2 August 2016,
when a British era masonry arch bridge failed during monsoon flood and carried
two state transport buses and several private vehicles into the river.
Recovery took days, for precisely these reasons.

Optical imaging is not a candidate. At the suspended sediment concentrations
of a monsoon flood, modelled here at \SI{\siteSSC}{\gram\per\litre}, visibility
is effectively zero. The system is therefore built around acoustic perception
throughout.

\keyfig{../cad/varuna_scene.png}
{The survey reach the vehicle was designed for, at a vertical exaggeration of
2.6. Three intact piers and one collapsed pier, shown in orange, stand on the
modelled bathymetry, and the scour hollows around the pier bases are part of
that model rather than an annotation. The orange track is the trajectory
actually flown in the reference mission, logged from the simulator, not a
sketch of a survey pattern.}{fig:scene}

\subsection{Statutory driver}

Beyond emergency response, IRC:SP:35 requires periodic underwater inspection
of bridge foundations, and the Dam Safety Act 2021 mandates inspection of
submerged structures. Scour depth is the quantity that determines whether a
pier is at risk. Measuring it currently requires divers or reservoir drawdown.
In the system described here it falls out of a routine survey automatically,
which converts an occasional, hazardous, qualitative inspection into a
repeatable quantitative measurement.

\keyfig{../simulation/results/figures/f0_architecture.png}
{System architecture. The vehicle acts only on estimated quantities; ground
truth is used solely to score the result afterwards.}{fig:arch}

% ======================================================================
\section{Why the standard platform does not work}

Proposals in this space normally assume an open frame commercial ROV of the
BlueROV2 class. The first engineering result of this work is that such a
vehicle cannot perform the mission, and the reason is not control tuning but
installed thrust against hydrodynamic drag.

For steady motion the surge drag is $X_{u}v + X_{u|u|}v|v|$. Setting this
equal to the largest pure surge wrench the thruster layout can produce before
any single thruster saturates gives the maximum current the vehicle can hold
station against. For the open frame baseline this is
\SI{0.96}{\metre\per\second}. The modelled site runs at
\SI{\siteCurrent}{\metre\per\second} at the surface. The vehicle is swept away,
and no controller can prevent it.

\keyfig{../simulation/results/figures/f5_vehicle.png}
{Left: surge drag against current speed for both vehicles, with the saturated
thrust limit of each. The intersection is the maximum holdable current. The
open frame baseline is out of envelope at the design condition by a factor of
more than two. Right: thruster utilisation over the reference mission for the
purpose designed vehicle.}{fig:vehicle}

\subsection{The design response}

Two changes recover the envelope, and a third is forced by the first:

\begin{itemize}[leftmargin=*,itemsep=2pt]
\item \textbf{Faired hull.} Axial quadratic drag is reduced by roughly a
factor of four relative to an open frame. Drag is deliberately left high
broadside, which also gives useful passive weathervaning into the flow.
\item \textbf{Larger thrusters and longer moment arms.} Force and torque share
one thrust budget, so moment arms are sized to buy attitude authority without
consuming the surge thrust that holds the vehicle in the current.
\item \textbf{Fixed stabilising fins.} A faired hull is directionally
unstable. The added mass asymmetry between axial and transverse directions
produces a destabilising Munk moment proportional to
$(Z_{\dot w} - X_{\dot u})\,u_r w_r$ whenever the hull moves at an angle of
attack. Buoyancy restoring is far too weak to counter it. Fins are therefore a
requirement, not a refinement, and they only stabilise when the vehicle flies
nose first.
\end{itemize}
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

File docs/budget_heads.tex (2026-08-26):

% Generated by cad/bom.py. Do not edit.
\begin{tabular}{lrrrrr}
\toprule
\textbf{Budget head} & \textbf{Months 1--6} & \textbf{7--12} & \textbf{13--18} & \textbf{19--24} & \textbf{Total} \\
\midrule
Equipment & 19.47 & 30.22 & 0.00 & 0.00 & 49.69 \\
Manpower & 1.86 & 3.72 & 3.72 & 1.86 & 11.16 \\
Consumables & 5.93 & 3.44 & 1.15 & 1.15 & 11.67 \\
Travel & 1.34 & 1.05 & 1.86 & 1.86 & 6.12 \\
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

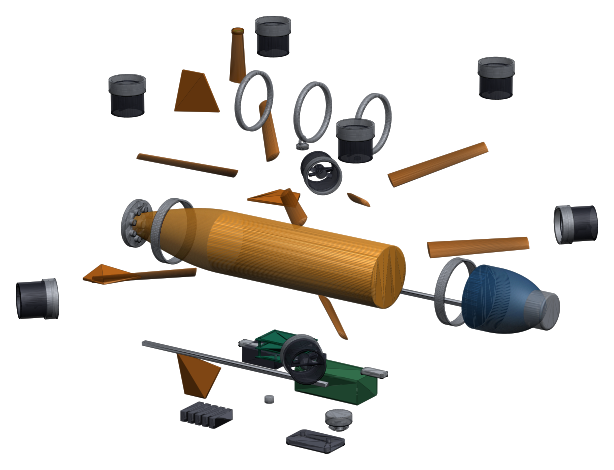
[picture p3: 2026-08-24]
cad/isonavi_exploded.png

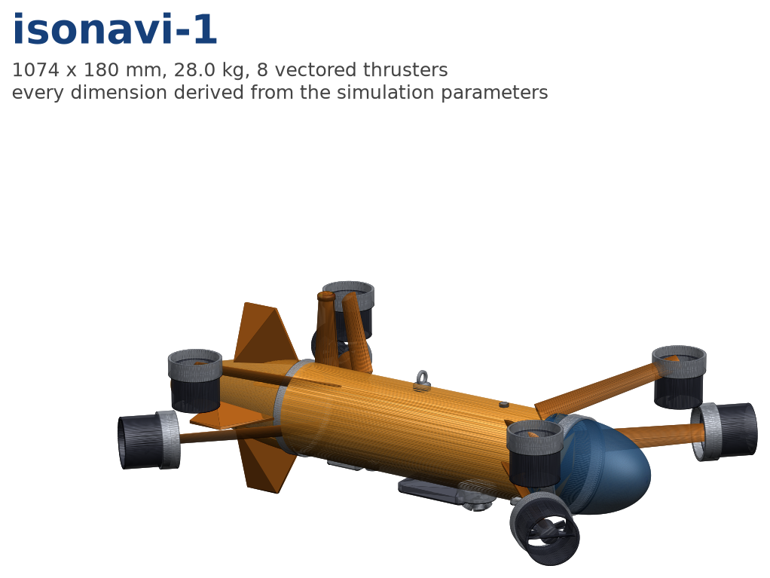
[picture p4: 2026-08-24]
cad/isonavi_hero.png

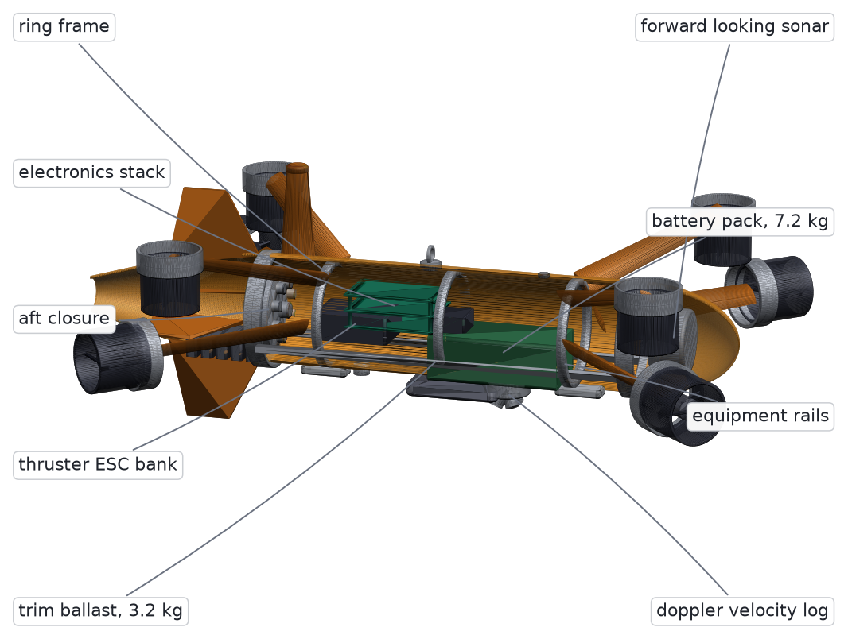
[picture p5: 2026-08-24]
cad/isonavi_cutaway.png

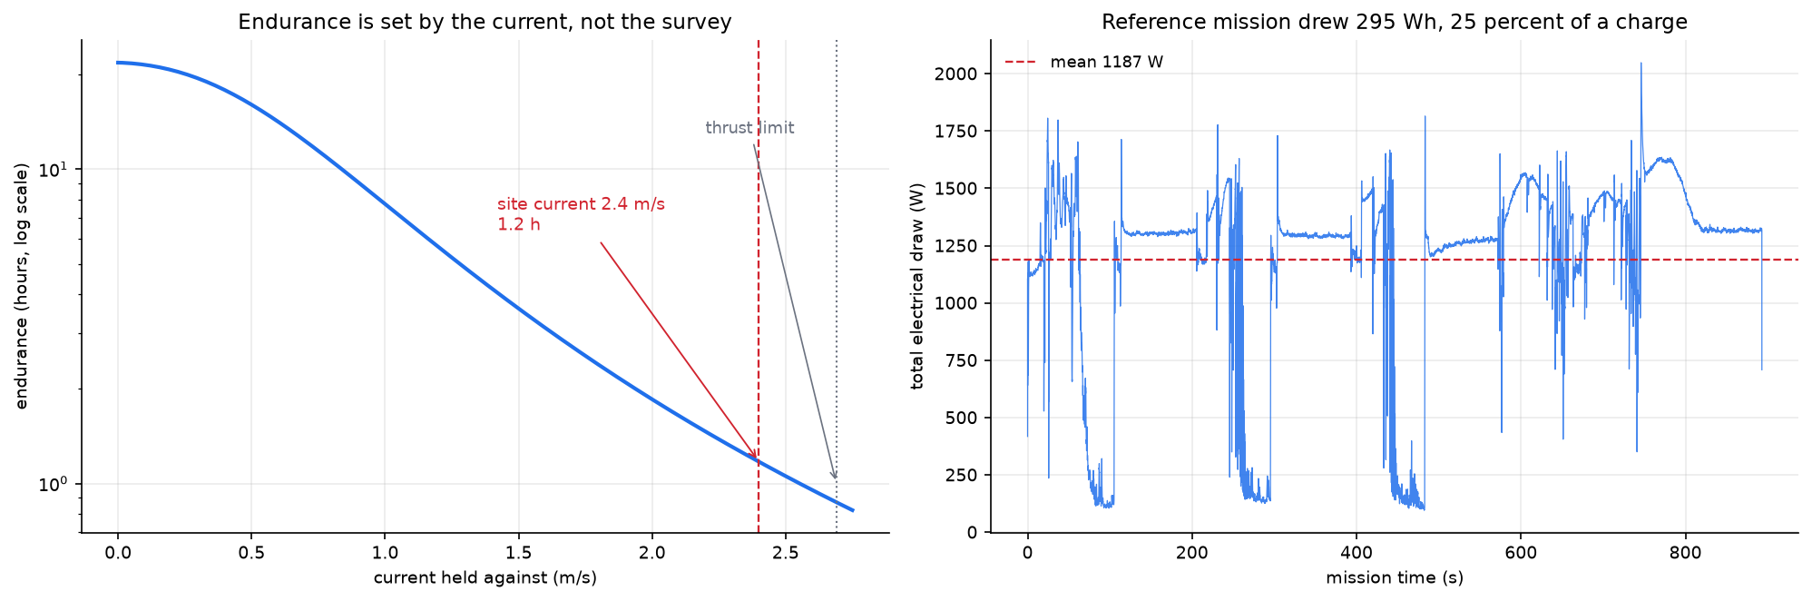
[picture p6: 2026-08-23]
cad/isonavi_energy.png

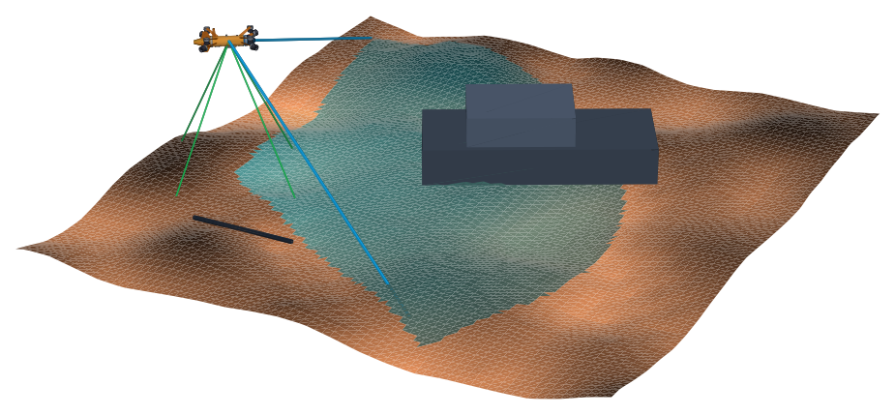
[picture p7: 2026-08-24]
cad/isonavi_detection.png

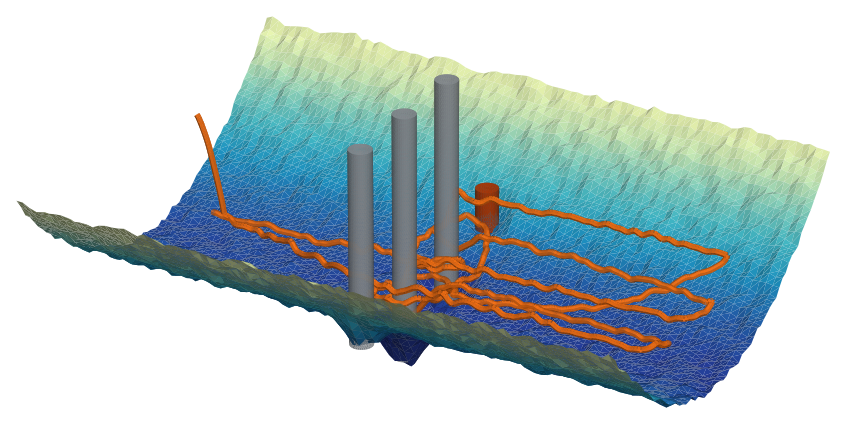
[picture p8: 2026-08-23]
cad/isonavi_scene.png

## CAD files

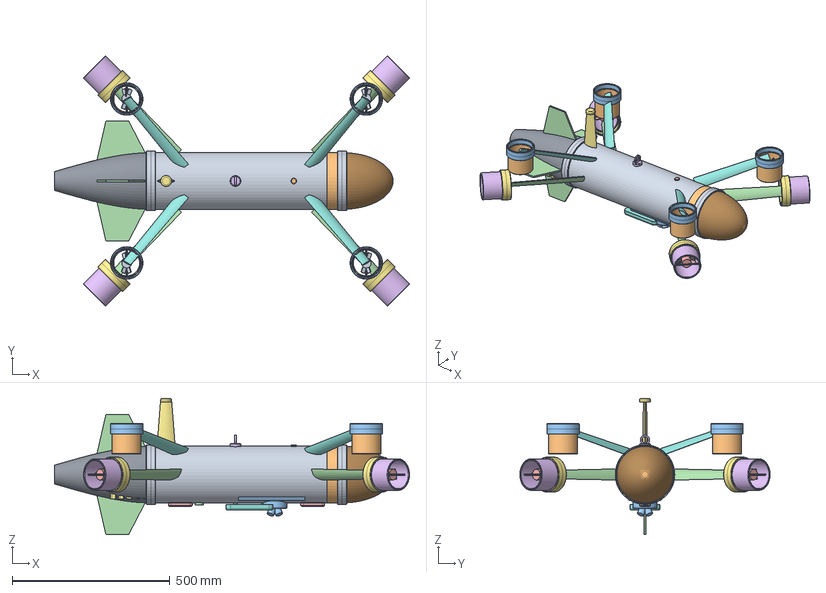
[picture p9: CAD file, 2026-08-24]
cad/isonavi_vehicle.step
1126.0 x 793.9 x 432.7 mm

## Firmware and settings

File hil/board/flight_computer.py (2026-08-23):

"""Flight computer for the LicheeRV Nano.

This is the code that runs on real hardware. It owns the estimation, control
and mission logic, and it is the real-time master of the loop: each tick it
asks the host for a sensor sample, runs the EKF and controller, allocates
thrust, sends pulse widths to the ESP32, and reports the applied wrench back to
the host so the host can integrate the plant.

It imports the same isonavi estimation, control and dynamics code that the
pure-simulation stack uses. Nothing is reimplemented for the board, so a
matching mission result is evidence about the same software, not a lookalike.

The board never receives ground truth. It sees only the sensor sample and acts
on its own estimate, exactly as the flight software would at sea.
"""

from __future__ import annotations

import argparse
import socket
import struct
import sys
import time

import numpy as np

sys.path.insert(0, "/root/hil")
sys.path.insert(0, "/root/hil/common")

import hil_protocol as P
from isonavi.estimation import NavigationEKF
from isonavi.control import PoseController, isonavi_GAINS, CurrentEstimator
from isonavi.dynamics import isonavi_1, vectored_allocation
from isonavi.mission import MissionConfig, lawnmower, orbit, PHASES
from isonavi.dynamics import rot_body_to_world


def thrust_to_pwm(force_n, max_n=120.0):
    """Map a per-thruster force in newtons to an ESC pulse width in us.

    Bidirectional ESC convention: 1500 us neutral, 1100 full reverse, 1900
    full forward, linear in between. This is what the ESP32 will output.
    """
    frac = float(np.clip(force_n / max_n, -1.0, 1.0))
    return int(round(1500 + frac * 400))


class SerialLink:
    """Link to the ESP32 actuator interface.

    Accepts either a serial device, which is how it is wired on the vehicle,
    or ``tcp:host:port``, which is how the bench reaches it: the ESP32
    enumerates on the Windows host while this board is a USB network device,
    so the frames cross a transparent socket bridge instead of a UART. The
    bytes on the wire are identical either way.
    """

    def __init__(self, dev, baud=115200):
        self.dev = dev
        self.kind = "none"
        self.ser = None
        self.sock = None
        self.dec = P.FrameDecoder()
        self.sent = 0
        self.echoes = 0
        self.mismatches = 0
        self.worst_err = 0
        self.unanswered = 0
        self.matched = 0
        self.lag_sum = 0
        self.lag_max = 0
        self.trace = []
        # Commands awaiting their echo, oldest first.
        self.q_cmd = []
        self.ring = []
        if not dev:
            return
        if dev.startswith("tcp:"):
            try:
                import socket
                _, host, port = dev.split(":")
                self.sock = socket.create_connection((host, int(port)),
                                                     timeout=5)
                self.sock.setsockopt(socket.IPPROTO_TCP, socket.TCP_NODELAY, 1)
                self.sock.setblocking(False)
                self.kind = "tcp"
                print(f"[esp32] bridged over {host}:{port}")
            except Exception as e:
                print(f"[esp32] bridge connect failed: {e}, running without")
        else:
            try:
                import serial
                self.ser = serial.Serial(dev, baud, timeout=0)
                self.kind = "uart"
                print(f"[esp32] serial {dev} at {baud}")
            except Exception as e:
                print(f"[esp32] serial open failed: {e}, running without")

    @property
    def active(self):
        return self.kind != "none"

    def send_pwm(self, widths):
        if not self.active:
            return
        frame = P.encode(P.MSG_PWM, P.pack_pwm(widths))
        try:
            if self.ser:
                self.ser.write(frame)
            else:
                self.sock.sendall(frame)
            self.sent += 1
            self.q_cmd.append(list(widths))
            self.ring.append(list(widths))
            if len(self.ring) > 32:
                del self.ring[:len(self.ring) - 32]
            # Bound the queue: if the actuator stops answering, the backlog
            # should not grow without limit.
            if len(self.q_cmd) > 64:
                del self.q_cmd[:len(self.q_cmd) - 64]
        except Exception:
            pass

    def poll_echo(self):
        """Non-blocking. The control loop never waits on the actuator."""
        if not self.active:
            return None
        try:
            if self.ser:
                n = self.ser.in_waiting
                data = self.ser.read(n) if n else b""
            else:
                try:
                    data = self.sock.recv(4096)
                except BlockingIOError:
                    data = b""
        except Exception:
            return None
        if not data:
            return None
        got = None
        for mt, pl in self.dec.feed(data):
            if mt == P.MSG_PWM_ECHO:
                got = P.unpack_pwm(pl)
                self.echoes += 1

                # Compare against a ring of recent commands rather than a
                # strict queue. The strict version required each echo to
                # answer the oldest outstanding command; when thrust is
                # changing by tens of microseconds per tick, an echo that
                # legitimately answers a neighbouring command then counts as a
                # fault. What matters is whether the hardware reproduced a
                # command it was actually given.
                hit = -1
                for i in range(len(self.ring) - 1, -1, -1):
                    if max(abs(x - y)
                           for x, y in zip(got, self.ring[i])) <= 2:
                        hit = len(self.ring) - 1 - i
                        break
                if hit < 0:
                    self.mismatches += 1
                    if self.ring and len(self.trace) < 6:
                        ref = self.ring[-1]
                        self.worst_err = max(
                            self.worst_err,
                            max(abs(x - y) for x, y in zip(got, ref)))
                        self.trace.append({"echo": list(got),
                                           "latest_cmd": list(ref)})
                else:
                    self.matched += 1
                    self.lag_sum += hit
                    self.lag_max = max(self.lag_max, hit)
        return got


class HostLink:
    """TCP link to the host plant. The board connects; the host listens."""

    def __init__(self, host, port):
        self.sock = socket.create_connection((host, port), timeout=10)
        self.sock.setsockopt(socket.IPPROTO_TCP, socket.TCP_NODELAY, 1)
        self.dec = P.FrameDecoder()
        self._pending = []

    def send(self, msg_type, payload):
        self.sock.sendall(P.encode(msg_type, payload))

    def recv_frame(self, want_type, timeout=5.0):
        """Block until a frame of want_type arrives."""
        self.sock.settimeout(timeout)
        while True:
            for mt, pl in self._pending:
                if mt == want_type:
                    self._pending.remove((mt, pl))
                    return pl
            data = self.sock.recv(4096)
            if not data:
                raise ConnectionError("host closed")
            self._pending += self.dec.feed(data)


class FlightComputer:
    def __init__(self, host, port, esp_dev, cfg=None, pier_y=None, seed=0):
        self.link = HostLink(host, port)
        self.esp = SerialLink(esp_dev)
        self.cfg = cfg or MissionConfig()
        # Pier cross-stream positions for the inspection orbits. The host is
        # the authority on site geometry, so these are supplied rather than
        # hardcoded on the board. Defaults match the reference site.
        self.pier_y = pier_y or {"P1": -24.0, "P2": -8.0, "P3": 8.0, "P4": 24.0}
        self.params = isonavi_1
        self.B = vectored_allocation(self.params.arms)
        self.Bp = np.linalg.pinv(self.B)

        launch = np.array(self.cfg.launch, float)
        yaw0 = CurrentEstimator.heading_into_flow(np.array([1.0, 0, 0])) or np.pi
        self.ekf = NavigationEKF(p0=launch)
        self.ekf.x[6:9] = np.array([0.0, 0.0, yaw0])
        self.ctl = PoseController(isonavi_GAINS, params=self.params)
        self.cest = CurrentEstimator(self.params.quad_damp, self.params.lin_damp)

        self.phase = "DEPLOY"
        self.tick = 0
        self.t = 0.0
        self.dt = self.cfg.dt
        self.wps = []
        self.wi = 0
        self.pier_queue = list(self.cfg.piers_to_inspect)
        self.current_pier = None
        self._phase_t0 = 0.0
        self.timing = []

    # -- the same allocation the plant uses, so wrench maps to the same forces
    def allocate(self, tau):
        """Force-prioritised thrust allocation, computed in closed form.

        The pure-simulation version found the largest torque scale by a 24-step
        bisection. That is a Python loop over matrix-vector products, which on
        the 750 MHz board costs about 9 ms, most of the loop budget. The same
        answer is available in closed form: the largest s in [0, 1] such that
        every |f_force_i + s f_torque_i| <= lim is the tightest per-thruster
        bound, so it is one vectorised min over the eight thrusters rather than
        an iterated search. Bit-for-bit identical to the bisection limit and
        about 20x faster.
        """
        lim = self.params.max_thrust_n
        Bp = self.Bp
        f_force = Bp[:, :3] @ tau[:3]
        f_torque = Bp[:, 3:] @ tau[3:]
        peak_f = np.max(np.abs(f_force))
        if peak_f > lim:
            return f_force * (lim / peak_f)
        # For each thruster, the s at which it saturates in either direction.
        with np.errstate(divide="ignore", invalid="ignore"):
            s_pos = (lim - f_force) / f_torque
            s_neg = (-lim - f_force) / f_torque
        cand = np.where(f_torque > 0, s_pos, s_neg)
        cand = cand[np.isfinite(cand) & (f_torque != 0)]
        s = 1.0 if cand.size == 0 else float(min(1.0, max(0.0, cand.min())))
        return f_force + s * f_torque

    def _depth_setpoint(self, altitude, bed_z):
        return bed_z + altitude

    def _target(self, bed_z):
        c = self.cfg
        est = self.ekf.position
        if self.phase in ("DEPLOY", "ACQUIRE"):
            return np.array([est[0], est[1], self._depth_setpoint(c.survey_altitude, bed_z)])
        if self.phase in ("SEARCH", "INSPECT"):
            xy = self.wps[self.wi] if self.wi < len(self.wps) else est[:2]
            alt = c.inspect_altitude if self.phase == "INSPECT" else c.survey_altitude
            return np.array([xy[0], xy[1], self._depth_setpoint(alt, bed_z)])
        if self.phase == "RETURN":
            xy = np.array(c.launch[:2])
            return np.array([xy[0], xy[1], self._depth_setpoint(c.survey_altitude, bed_z)])
        return est

    def _advance(self, tgt):
        c = self.cfg
        est = self.ekf.position
        d = float(np.linalg.norm(est - tgt))
        dtp = self.t - self._phase_t0
        if self.phase == "DEPLOY":
            if abs(est[2] - tgt[2]) < 1.0:
                self.phase, self._phase_t0 = "ACQUIRE", self.t
        elif self.phase == "ACQUIRE":
            if dtp > 6.0:
                x0, x1, y0, y1 = c.search_box
                self.wps = lawnmower(x0, x1, y0, y1, c.lawnmower_spacing)
                self.wi = 0
                self.phase, self._phase_t0 = "SEARCH", self.t
        elif self.phase in ("SEARCH", "INSPECT"):
            if d < c.waypoint_radius or dtp > 400:
                self.wi += 1
                self._phase_t0 = self.t
            if self.wi >= len(self.wps):
                if (self.phase == "SEARCH" or self.phase == "INSPECT") and self.pier_queue:
                    self.current_pier = self.pier_queue.pop(0)
                    py = self.pier_y[self.current_pier]
                    self.wps = orbit((0.0, py), c.pier_standoff, c.orbit_points)
                    self.wi = 0
                    if self.phase == "SEARCH":
                        self.phase = "INSPECT"
                    self._phase_t0 = self.t
                else:
                    self.phase, self._phase_t0 = "RETURN", self.t
        elif self.phase == "RETURN":
            if d < 3.0 or dtp > 260:
                self.phase, self._phase_t0 = "REPORT", self.t
        elif self.phase == "REPORT":
            self.phase = "DONE"

    def run(self, max_time):
        self.link.send(P.MSG_HELLO, struct.pack("<if", 1, 1.0 / self.dt))
        self.t_wait = []
        self.t_esp = []   # time blocked waiting for the host's sensor reply
        self.t_comp = []   # time in estimation + control + allocation
        while self.phase != "DONE" and self.t < max_time:
            t0 = time.perf_counter()

            self.link.send(P.MSG_SENSOR_REQ, P.pack_sensor_req(self.t))
            s = P.unpack_sensor(self.link.recv_frame(P.MSG_SENSOR))
            t_after_wait = time.perf_counter()
            self.t_wait.append((t_after_wait - t0) * 1000.0)

            # Apply exactly the corrections the sensors reported this tick,
            # matching the pure-simulation loop: IMU drives predict+attitude,
            # a tick with no IMU still predicts on the last gyro, DVL corrects
            # velocity only under bottom lock, depth corrects z.
            if s["has_imu"]:
                self.ekf.predict(np.array(s["gyro"]), self.dt)
                self.ekf.update_attitude(np.array(s["att"]))
            else:
                self.ekf.predict(self.ekf.last_gyro, self.dt)
            if s["dvl_lock"]:
                self.ekf.update_dvl(np.array(s["dvl_v"]))
            if s["has_depth"]:
                self.ekf.update_depth(s["depth"])

            # Held DVL altitude gives the bed height under the vehicle for
            # terrain following.
            bed_z = self.ekf.position[2] - s["dvl_alt"]
            tgt = self._target(bed_z)
            yaw = CurrentEstimator.heading_into_flow(self.cest.v)
            if yaw is None:
                yaw = self.ekf.attitude[2]
            tau = self.ctl.compute(self.ekf.position, self.ekf.attitude,
                                   self.ekf.velocity_body, tgt, yaw, self.dt,
                                   current_ff=self.cest.v)
            f = self.allocate(tau)
            self.cest.update(tau[:3], self.ekf.velocity_body, self.ekf.attitude)

            widths = [thrust_to_pwm(fi, self.params.max_thrust_n) for fi in f]
            # Time the actuator link on its own, so the cost of the bench
            # transport can be separated from the control computation.
            t_esp0 = time.perf_counter()
            self.esp.send_pwm(widths)
            # Non-blocking: whatever the actuator has echoed since last tick is
            # collected here, so the control loop never waits on it.
            self.esp.poll_echo()
            self.t_esp.append((time.perf_counter() - t_esp0) * 1000.0)

            self.link.send(P.MSG_THRUST, P.pack_thrust(tau.tolist(), f.tolist()))
            self.link.send(P.MSG_STATE, P.pack_state(
                self.ekf.position.tolist(), self.ekf.attitude.tolist(),
                self.ekf.horizontal_uncertainty, PHASES.index(self.phase),
                self.tick))

            self._advance(tgt)
            self.t += self.dt
            self.tick += 1
            now = time.perf_counter()
            self.timing.append((now - t0) * 1000.0)
            self.t_comp.append((now - t_after_wait) * 1000.0)

        self.link.send(P.MSG_STATE, P.pack_state(
            self.ekf.position.tolist(), self.ekf.attitude.tolist(),
            self.ekf.horizontal_uncertainty, PHASES.index("DONE"), self.tick))
        return self.report()

    def report(self):
        ti = np.array(self.timing)
        return {
            "ticks": self.tick,
            "sim_time": self.t,
            "phase": self.phase,
            "loop_ms_mean": float(ti.mean()) if len(ti) else 0.0,
            "loop_ms_p99": float(np.percentile(ti, 99)) if len(ti) else 0.0,
            "loop_ms_max": float(ti.max()) if len(ti) else 0.0,
            "compute_ms_mean": float(np.mean(self.t_comp)) if self.t_comp else 0.0,
            "compute_ms_p99": float(np.percentile(self.t_comp, 99)) if self.t_comp else 0.0,
            "wait_ms_mean": float(np.mean(self.t_wait)) if self.t_wait else 0.0,
            "budget_ms": self.dt * 1000.0,
            "esp_ms_mean": (float(np.mean(self.t_esp))
                            if self.t_esp else 0.0),
            "esp_ms_p99": (float(np.percentile(self.t_esp, 99))
                           if self.t_esp else 0.0),
            "esp_link": self.esp.kind,
            "esp_pwm_sent": self.esp.sent,
            "esp_echoes": self.esp.echoes,
            "esp_mismatches": self.esp.mismatches,
            "esp_worst_width_err_us": self.esp.worst_err,
            "esp_matched": self.esp.matched,
            "esp_lag_mean": (self.esp.lag_sum / self.esp.matched
                             if self.esp.matched else 0.0),
            "esp_lag_max": self.esp.lag_max,
            "esp_trace": self.esp.trace,
            "esp_crc_errors": self.esp.dec.crc_errors,
            "host_crc_errors": self.link.dec.crc_errors,
        }


if __name__ == "__main__":
    ap = argparse.ArgumentParser()
    ap.add_argument("--host", default="10.133.84.100")
    ap.add_argument("--port", type=int, default=5555)
    ap.add_argument("--esp", default="/dev/ttyS1")
    ap.add_argument("--max-time", type=float, default=1000.0)
    args = ap.parse_args()

    fc = FlightComputer(args.host, args.port, args.esp)
    import json
    rep = fc.run(args.max_time)
    print("REPORT " + json.dumps(rep))

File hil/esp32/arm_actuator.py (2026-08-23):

"""Start the ESP32 actuator loop through the bridge, then leave it running.

The bridge is a transparent pipe, so the MicroPython raw REPL is reachable
across it exactly as it is over the wire. Arming is kept as a separate step
rather than an autostart on boot, because a loop that owns the console from
power-on removes the recovery path; this way a plain reset always lands back
at a REPL.
"""

import argparse
import socket
import struct
import time

SYNC0, SYNC1 = 0xA5, 0x5A
MSG_PWM_ECHO = 0x31


def crc16(d, c=0xFFFF):
    for b in d:
        c ^= b << 8
        for _ in range(8):
            c = ((c << 1) ^ 0x1021) & 0xFFFF if c & 0x8000 \
                else (c << 1) & 0xFFFF
    return c


def read_for(s, seconds):
    buf = bytearray()
    t0 = time.time()
    s.settimeout(0.05)
    while time.time() - t0 < seconds:
        try:
            d = s.recv(4096)
            if not d:
                break
            buf.extend(d)
        except socket.timeout:
            pass
        except Exception:
            break
    return bytes(buf)


def encode(mt, pl):
    h = struct.pack("<BH", mt, len(pl))
    return bytes([SYNC0, SYNC1]) + h + pl + struct.pack("<H", crc16(h + pl))


def find_echo(buf):
    i = buf.find(bytes([SYNC0, SYNC1]))
    while i >= 0 and len(buf) >= i + 23:
        if buf[i + 2] == MSG_PWM_ECHO:
            return list(struct.unpack("<8H", bytes(buf[i + 5:i + 21])))
        i = buf.find(bytes([SYNC0, SYNC1]), i + 1)
    return None


def arm(host, port, timeout=12.0):
    s = socket.create_connection((host, port), timeout=6)
    s.setsockopt(socket.IPPROTO_TCP, socket.TCP_NODELAY, 1)

    # Arming is idempotent. A loop left running from an earlier run has Ctrl-C
    # disabled, so probing it is the only way to tell it apart from a board
    # sitting at a REPL; a neutral command is harmless either way.
    s.sendall(encode(0x30, struct.pack("<8H", *([1500] * 8))))
    probe = bytearray(read_for(s, 1.2))
    already = find_echo(probe)
    if already is not None:
        print(f"[arm] actuator already running, channels at {already} us")
        s.close()
        return True

    # Interrupt anything running, enter the raw REPL, start the loop.
    s.sendall(b"\x03\x03")
    read_for(s, 0.4)
    s.sendall(b"\x01")
    out = read_for(s, 0.8)
    if b"raw REPL" not in out:
        print("[arm] no raw REPL prompt; is the board in a running loop?")
    s.sendall(b"import actuator\nactuator.run()\x04")

    # The loop announces itself with one echo frame carrying the armed state.
    t0 = time.time()
    buf = bytearray()
    while time.time() - t0 < timeout:
        buf.extend(read_for(s, 0.3))
        i = buf.find(bytes([SYNC0, SYNC1]))
        if i >= 0 and len(buf) >= i + 23:
            f = buf[i:i + 23]
            if f[2] == MSG_PWM_ECHO:
                widths = struct.unpack("<8H", bytes(f[5:21]))
                print(f"[arm] actuator armed, channels at {list(widths)} us")
                s.close()
                return True
    print("[arm] no armed frame seen")
    s.close()
    return False


if __name__ == "__main__":
    ap = argparse.ArgumentParser()
    ap.add_argument("--host", default="127.0.0.1")
    ap.add_argument("--port", type=int, default=5558)
    a = ap.parse_args()
    raise SystemExit(0 if arm(a.host, a.port) else 1)

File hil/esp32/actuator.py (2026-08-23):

"""isonavi actuator interface, running on the ESP32.

Speaks the same framed, CRC checked protocol as the rest of the bench, so the
pulse widths this generates are the ones the flight computer's allocation
actually produced, carried over the same wire format rather than a second,
friendlier one written for the demo.

Eight LEDC channels at the standard 50 Hz ESC frame. On each command the duty
registers are read back and converted to microseconds, so the echo reports what
the hardware is really emitting rather than what it was told to emit. That
distinction is the point of putting a real part in the loop.

Console handling, which took two attempts to get right on this chip:

  * ``os.dupterm(None, 1)`` is wrong here. On ESP32 the console slot is 0, and
    index 1 raises ValueError.
  * Re-opening ``machine.UART(0)`` is also wrong: the console driver already
    owns UART0 and a second open fails with ESP_ERR_INVALID_STATE.

Neither is necessary. While this loop is running the REPL is not parsing input,
so the running program already owns stdin. The only thing in the way is that a
0x03 byte inside a binary frame would raise KeyboardInterrupt, which
``micropython.kbd_intr(-1)`` disables for the duration.
"""

import struct
import sys
import time

from machine import Pin, PWM

# Eight ESC outputs. Chosen to avoid the strapping pins (0, 2, 12, 15) and the
# input-only pins (34 to 39), so nothing here disturbs boot.
ESC_PINS = (13, 14, 16, 17, 18, 19, 21, 22)
FREQ = 50                       # standard ESC frame, 20 ms
PERIOD_US = 1000000 // FREQ
DUTY_BITS = 16
DUTY_MAX = (1 << DUTY_BITS) - 1

SYNC0, SYNC1 = 0xA5, 0x5A
MSG_PWM = 0x30
MSG_PWM_ECHO = 0x31

NEUTRAL_US = 1500
MIN_US, MAX_US = 1000, 2000


def crc16_ccitt(data, crc=0xFFFF):
    for b in data:
        crc ^= b << 8
        for _ in range(8):
            crc = ((crc << 1) ^ 0x1021) & 0xFFFF if (crc & 0x8000) \
                else (crc << 1) & 0xFFFF
    return crc


def encode(msg_type, payload):
    header = struct.pack("<BH", msg_type, len(payload))
    crc = crc16_ccitt(header + payload)
    return bytes([SYNC0, SYNC1]) + header + payload + struct.pack("<H", crc)


def us_to_duty(us):
    """Microseconds to a 16 bit duty word, rounded rather than truncated.

    One LSB is 20000/65535 = 0.305 us at this frame rate, so rounding keeps the
    round trip inside half a microsecond instead of biasing every channel low.
    """
    us = MIN_US if us < MIN_US else (MAX_US if us > MAX_US else us)
    return (us * DUTY_MAX + PERIOD_US // 2) // PERIOD_US


def duty_to_us(duty):
    return (duty * PERIOD_US + DUTY_MAX // 2) // DUTY_MAX


class Actuators:
    """Eight ESC channels, armed at neutral."""

    def __init__(self, settle_ms=300):
        self.ch = []
        for p in ESC_PINS:
            pwm = PWM(Pin(p), freq=FREQ)
            pwm.duty_u16(us_to_duty(NEUTRAL_US))
            self.ch.append(pwm)
        # The LEDC duty registers do not latch instantly. Reading them before
        # they do reports zero, which looks like a dead channel and is not.
        time.sleep_ms(settle_ms)

    def apply(self, widths):
        for pwm, w in zip(self.ch, widths):
            pwm.duty_u16(us_to_duty(w))

    def readback(self):
        """What the hardware is actually emitting, from the duty registers."""
        return [duty_to_us(pwm.duty_u16()) for pwm in self.ch]

    def readback_then_apply(self, widths):
        """Report what the hardware currently holds, then command the new value.

        Waiting a full PWM period after each command to confirm it does give a
        true reading, but it blocks the interface for 21 ms and, at a 50 ms
        command interval, that back pressure pushed the flight computer's loop
        past its budget. Reading first costs nothing: by the time the next
        command arrives the previous one has long since latched, so the value
        reported is still measured from the duty registers rather than assumed.
        The echo simply answers the previous command, which the commander
        already accounts for as pipeline lag.
        """
        measured = self.readback()
        self.apply(widths)
        return measured

    def safe(self):
        for pwm in self.ch:
            pwm.duty_u16(us_to_duty(NEUTRAL_US))


class Decoder:
    """Same resynchronising decoder as the host side, in miniature."""

    def __init__(self):
        self.buf = bytearray()
        self.crc_errors = 0
        self.resyncs = 0

    def feed(self, data):
        """Consume bytes, return complete frames.

        The host side of this decoder deletes consumed bytes with ``del
        buf[:n]``. MicroPython's bytearray does not implement slice deletion,
        so the same line raises TypeError on the device; the buffer is rebuilt
        by slicing instead. Frames here are 23 bytes, so the copy is free.
        """
        out = []
        self.buf.extend(data)
        while True:
            b = self.buf
            n = len(b)
            if n < 5:
                return out
            if not (b[0] == SYNC0 and b[1] == SYNC1):
                i = self._find_sync(1)
                if i < 0:
                    self.buf = bytearray(b[-1:]) if n else bytearray()
                    return out
                self.buf = bytearray(b[i:])
                self.resyncs += 1
                continue
            mt = b[2]
            ln = b[3] | (b[4] << 8)
            total = 5 + ln + 2
            if n < total:
                if self._find_sync(2) >= 0:
                    self.buf = bytearray(b[2:])
                    self.resyncs += 1
                    continue
                return out
            payload = bytes(b[5:5 + ln])
            crc_rx = b[5 + ln] | (b[6 + ln] << 8)
            if crc_rx != crc16_ccitt(bytes(b[2:5]) + payload):
                self.crc_errors += 1
                self.buf = bytearray(b[2:])
                self.resyncs += 1
                continue
            self.buf = bytearray(b[total:])
            out.append((mt, payload))

    def _find_sync(self, start):
        b = self.buf
        for i in range(start, len(b) - 1):
            if b[i] == SYNC0 and b[i + 1] == SYNC1:
                return i
        return -1
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

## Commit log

2026-08-19 sonar simulator, vehicle dynamics and autonomous mission
2026-08-20 full mission results, perception experiments, report and video
    [train_curve.csv]
2026-08-21 reorganise repository into workstream directories
    [train_curve.csv]
2026-08-21 hardware in the loop on licheerv nano and parametric vehicle cad (#2)
    [varuna_vehicle.step]
2026-08-22 document hardware in the loop and vehicle cad in the report (#3)
2026-08-22 component level vehicle cad, corrected stability margin, honest detection metrics (#4)
    * component level vehicle cad with a solved mass and stability budget
    * correct the stability margin from the cad budget and report detection false alarms
    [varuna_vehicle.step]
2026-08-22 use the true hull centroid for trim and cross check the cad against the kernel (#5)
    [varuna_vehicle.step]
2026-08-22 size the pressure hull and the thruster pylons (#6)
2026-08-22 derive drag and added mass from the cad geometry and recheck the envelope (#7)
2026-08-23 model the ancillary hardware and place the vehicle in its site (#8)
    [varuna_vehicle.step]
2026-08-23 add the energy budget and the bill of materials (#9)
2026-08-23 analyse what a lost thruster costs and price the remedy (#10)
2026-08-23 make the actuator interface real and state the readiness position (#12)
2026-08-23 make the flowcharts legible at print size and give the exploded view a structure
2026-08-24 state the budget in rupees and close the mass and cost loops
    [isonavi_vehicle.step]
